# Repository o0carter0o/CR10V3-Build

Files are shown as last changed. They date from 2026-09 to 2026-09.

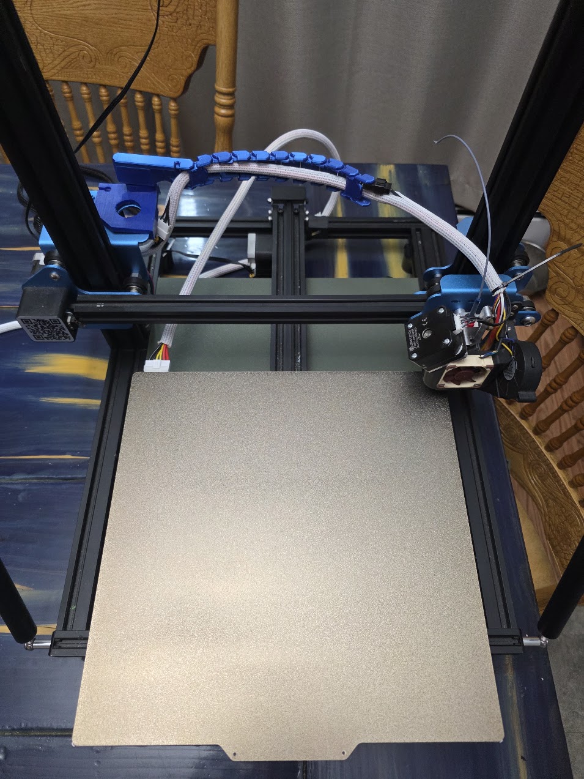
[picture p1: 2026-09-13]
images/20260907_123307.jpg

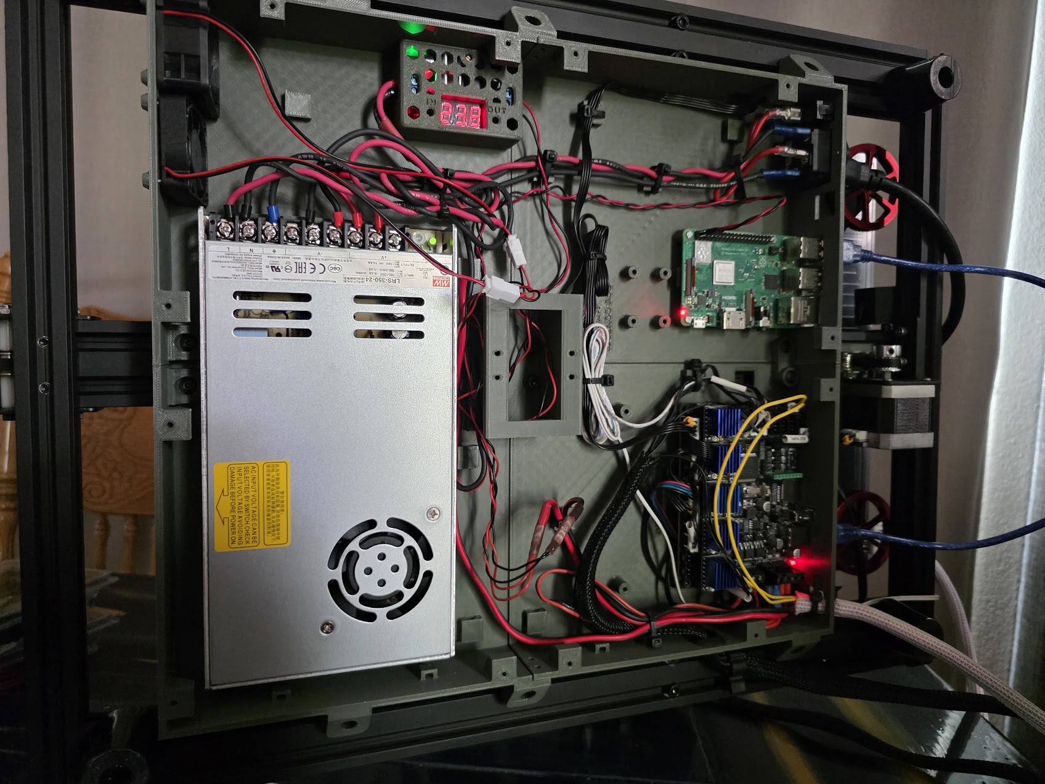
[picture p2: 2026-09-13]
images/20260911_142548.jpg

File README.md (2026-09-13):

# CR-10 V3 Under-Frame Electronics Conversion

This repository documents a CR-10 V3 conversion built around an MKS Robin Nano v3.1, independent dual Z, a Micro Swiss NG direct-drive extruder, CR Touch, and a four-piece printed under-frame electronics enclosure.

Current enclosure release: **v1.1**.

## Repository contents

- [`enclosure/STL/print_ready`](enclosure/STL/print_ready) — nine print-ready enclosure parts
- [`enclosure/STEP/assembled`](enclosure/STEP/assembled) — authoritative assembled STEP
- [`enclosure/STEP/parts_print_orientation`](enclosure/STEP/parts_print_orientation) — editable individual parts oriented for printing
- [`enclosure/STEP/parts_global`](enclosure/STEP/parts_global) — individual parts in installed coordinates
- [`enclosure/Accessories`](enclosure/Accessories) — opening blanks, Robin Nano spacers, and center-support adapter
- [`klipper`](klipper) — reference printer, macro, Mainsail, and Moonraker configuration snapshots
- [`docs/BUILD_GUIDE.md`](docs/BUILD_GUIDE.md) — printer and enclosure build overview
- [`docs/WIRING.md`](docs/WIRING.md) — board assignments and CR Touch wiring
- [`docs/ENCLOSURE_BOM.md`](docs/ENCLOSURE_BOM.md) — enclosure hardware list
- [`docs/ENCLOSURE_NOTES.md`](docs/ENCLOSURE_NOTES.md) — assembly and electrical notes

## Enclosure printing baseline

- 0.4 mm nozzle
- 0.20 mm layers
- At least 4 walls/perimeters
- At least 5 top and bottom layers
- Print the main parts in the supplied orientation
- The main parts are designed to print without supports

The assembled STEP is the authoritative v1.1 geometry. The STL files are the ready-to-print deliverables.

Part filenames use installed machine position, viewed from the front/operator side of the printer.

## Configuration warning

The files in `klipper/` are reference material for this specific machine. They are not a universal drop-in configuration. Verify the board revision, pin assignments, thermistor types, motor directions, travel limits, probe offsets, heater behavior, and emergency shutdown before moving any axis or heating anything.

At minimum, replace the MCU `serial:` path in `printer.cfg` with the path reported by your own controller.

## Safety

This conversion places AC mains wiring and a power supply in a printed enclosure. Use proper strain relief, insulated terminals, protective-earth bonding, fusing, wire sizes, separation, and continuity testing. Mains work should be performed only by someone qualified to do it.

## Attribution

This enclosure is a derivative of HeyRay2's [CR-10 V2 Control Box Eliminator - Standalone Conversion](https://www.thingiverse.com/thing:4347673). See [`ATTRIBUTION.md`](ATTRIBUTION.md).

## License

- STEP, STL, and documentation: [CC BY 4.0](LICENSE-CC-BY-4.0.txt)
- Klipper configuration and original macros: [GPL-3.0-or-later](LICENSE-GPL-3.0.txt)

See [`LICENSE.md`](LICENSE.md) for the file-by-file scope and third-party notices.

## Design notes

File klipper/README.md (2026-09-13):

# Klipper Configuration Snapshot

These files are reference material for this CR-10 V3 conversion. They are not guaranteed to be safe on another printer without review.

Before use:

- Set the correct MCU `serial:` path in `printer.cfg`.
- Confirm every pin assignment against your exact MKS Robin Nano v3.1 board.
- Verify motor direction, endstop state, thermistor type, heater behavior, probe operation, and emergency stop behavior.
- Do not heat or move the printer until the config is checked.

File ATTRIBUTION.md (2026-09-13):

# Attribution

This CR-10 V3 under-frame electronics enclosure is a derivative of:

- **CR-10 V2 Control Box Eliminator - Standalone Conversion**
- Creator: HeyRay2
- Source: https://www.thingiverse.com/thing:4347673
- License: Creative Commons Attribution 4.0 International

The published V1.0 enclosure has been substantially modified for this CR-10 V3 build, including a four-quadrant under-frame layout, MKS Robin Nano v3.1 mounting, Raspberry Pi 3B/3B+ mounting, MKS TS35 v2.0 screen opening, reused Creality mains/pass-through hardware, center support, direct-thread bosses, cable routing, and fan/vent changes.

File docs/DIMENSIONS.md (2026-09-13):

# V1.1 key dimensions and interfaces

- Development source revision: V1.1 publication package
- Closed enclosure height: 45.0 mm
- Shell height: 42.6 mm
- Nominal wall thickness: 3.2 mm
- Nominal ceiling thickness: 2.4 mm
- Primary split datums: X=160 mm, Y=170 mm
- Case placement datum: 40 mm Y setback from the inside face of the front frame extrusion
- Rear lid depth: 189.4 mm
- Fan footprint: 40 × 40 mm; fastener pitch 32 × 32 mm
- M4 frame/T-nut clearance: Ø4.5 mm
- M3 direct-thread pilot: Ø2.6 mm
- Screen cable opening: 19.27 × 10.4 mm
- Keystone throat: 14.8 × 16.5 mm
- Pi wall openings: 2 × 16.2 × 18.0 mm; 1 × 17.4 × 16.4 mm
- Raw-cable entry edge fillets: R0.75 mm at the approved five openings and local raceway mouths
- Rear bonding peg/socket XY clearance: 0.20 mm per side (0.40 mm diametral)
- Rear bonding hardware: M4×10

## V1.1 interface changes

- Left Rear rear keystone replaced by a second Ø17 mm grommet opening.
- Robin Nano mounting now uses four 5 mm spacers in either board position.
- Right Rear keystone moved slightly toward machine center and uses an internal snap-fit cage with a 45° printable underside.
- Right Rear includes a Ø4.5 mm frame-bond access hole and protective-earth symbol.

Part filenames use installed machine position, viewed from the front/operator side of the printer.

## Locked vertical-wall cable-tie anchor

- Single tie channel
- Exact forward/aft mirror symmetry
- Overall anchor width: 8.30 mm
- Projection from wall: 4.50 mm
- Tie gap: 4.20 mm
- Straight-leg section before roof transition: 0.00 mm
- Inner roof faces: 45°
- Outer support face: 45°
- Channel-roof to outer-top distance: 6.00 mm
- Unsupported bridge span: 1.20 mm

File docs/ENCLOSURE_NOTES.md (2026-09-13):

# V1.1 Notes

## Changes from V1.0

- Left Rear: rear keystone replaced by a second Ø17 mm grommet opening.
- Robin Nano: all eight optional mounting bosses now use the short geometry; use four 5 mm spacers in either board position.
- Right Rear: keystone moved slightly toward machine center and given an internal snap-fit cage with a 45° printable underside.
- Right Rear: added a Ø4.5 mm frame-bond access hole and protective-earth symbol.

Part filenames use installed machine position, viewed from the front/operator side of the printer. Earlier internal CAD/package naming had left and right reversed; this repo uses the corrected installed-position names.

## Assembly notes

- Insert the Left Rear keystone from inside the enclosure toward the exterior.
- The built-in zip-tie anchors are intended to print without support. Avoid support material inside the tie channels; it adds cleanup risk without helping the final part.
- Use the supplied print orientation for the shell quadrants and lids.
- Direct-thread the printed pilots carefully. Start screws square to the hole and avoid over-tightening.
- The center support clamps the inner quadrant corners to the central 20×40 extrusion from inside the enclosure.
- Twist the internal switched Line and Neutral run from the inlet/switch area to the PSU.
- Twist or closely couple the internal `+24 V / 0 V` pair from the PSU to the Robin Nano.
- If the keystone carries normal data, an inlet-mounted EMI filter or grounded L-shaped steel divider may be added if desired.
- If Cat6 carries steppers/endstops, keep each motor coil on one twisted pair and place endstop signal/ground on their own pair.

Frame bonding is an optional retrofit in this design and is strongly encouraged when modifying the mains enclosure. The designer's personal solution is a suitable self-tapping screw through the marked hole into the extrusion V-channel with a ring terminal and toothed washer. This permanently marks/cuts the extrusion and is not readily reversible.

Alternatives include enlarging the access for a conductive T-nut and ring terminal, drilling and tapping the frame, routing the bonding wire to another suitable frame location, or bonding the grounded PSU chassis to the printer frame. Any method must make reliable metal-to-metal contact; verify continuity after assembly. Mains work should be performed only by someone qualified to do it.

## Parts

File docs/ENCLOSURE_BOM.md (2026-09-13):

# Hardware BOM — V1.1

## Main components

| Qty | Component |
|---:|---|
| 1 | MKS Robin Nano v3.1 |
| 1 | Mean Well LRS-350-24 PSU |
| 1 | MKS TS35 v2.0 display |
| 1 | Raspberry Pi 3B/3B+ (optional) |
| 3 | 40 mm case fans; thickness and voltage to suit the build |
| 1 | OEM IEC inlet |
| 1 | OEM rocker switch |
| 1 | OEM heated-bed connector |
| 2 | OEM-style grommets for the Ø17 mm cable entries |
| 1 | Keystone jack or included blank (optional) |

## Fasteners

| Qty | Hardware | Use |
|---:|---|---|
| 16 | M3×8 | Four lids |
| 4 | M3×10 | Robin Nano through the included 5 mm spacers |
| 4 | M2.5×5 | Raspberry Pi |
| 4 | M3×8 | PSU-control board |
| 4 | M4×4 | PSU mounting; avoid excessive penetration |
| 8 | M4×10 plus T-nuts | Four exterior mounts and four center-support clamps |
| 1 | M4×10 | Rear quadrant bonding bridge |
| 9 | M3, length to suit fan thickness | Three screws per fan |
| 4 | M3×8 nominal | Optional center-support adapter |

## Printed accessories

Print four `Robin_Nano_Spacer_5mm_M3` spacers for either motherboard position. A ready-to-print 4× set is included.

Pilot standards: M3 direct-thread Ø2.6 mm; M2.5 direct-thread Ø2.2 mm; M4/T-nut clearance Ø4.5 mm.

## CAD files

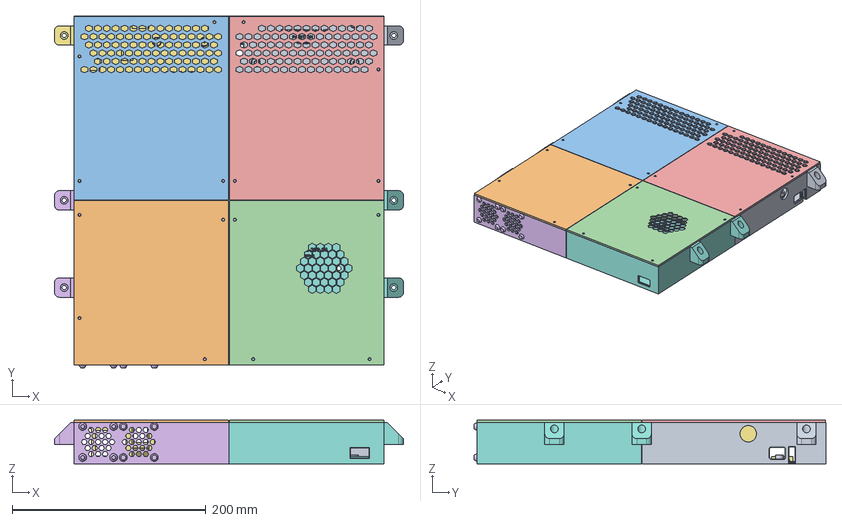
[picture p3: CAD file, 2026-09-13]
enclosure/STEP/assembled/CR10V3_Control_Box_V1.1_Assembled.step
360.0 x 362.8 x 45.0 mm

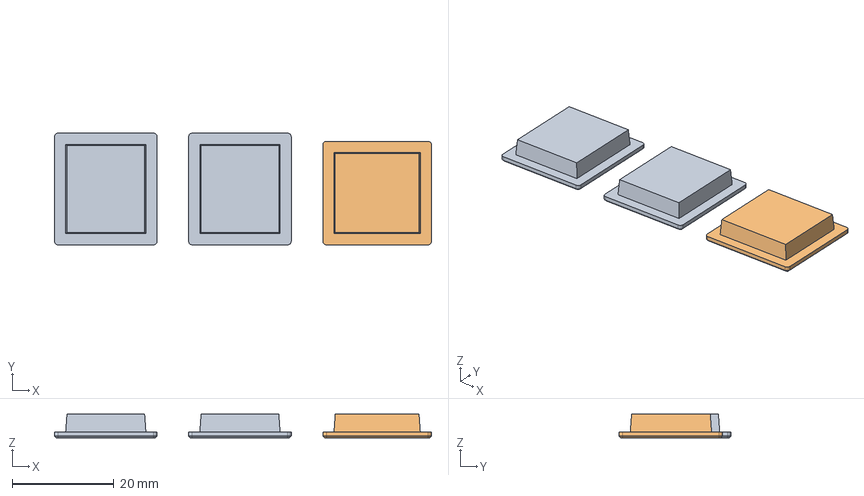
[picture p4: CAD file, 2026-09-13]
enclosure/Accessories/STEP/RPi_Blanks_Full_Set.step
74.2 x 22.0 x 4.70 mm

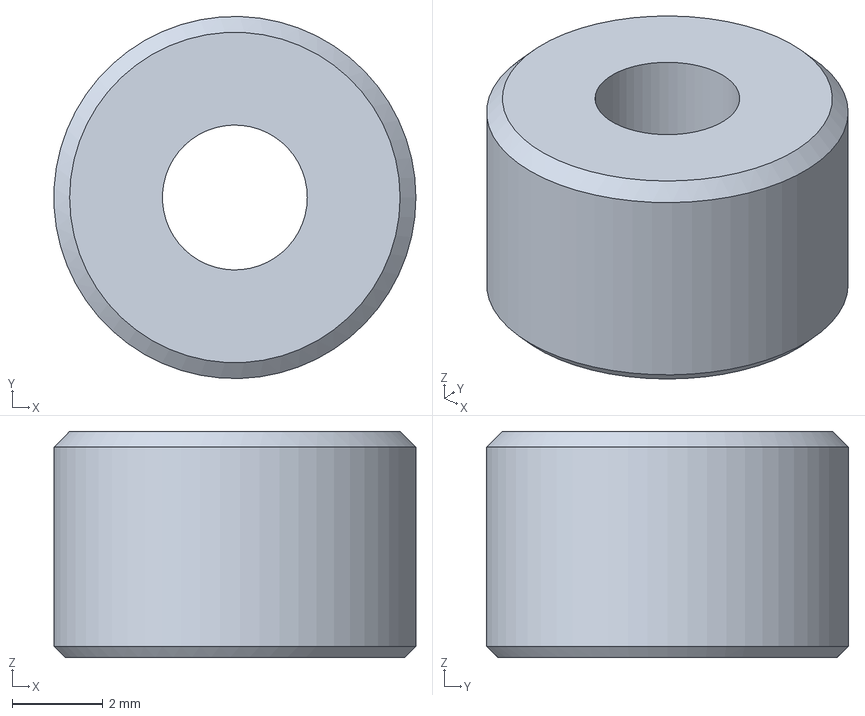
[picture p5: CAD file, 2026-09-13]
enclosure/Accessories/STEP/Robin_Nano_Spacer_5mm_M3.step
7.99 x 8.00 x 5.00 mm

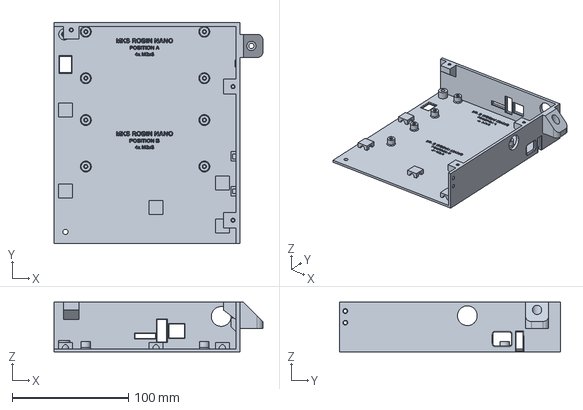
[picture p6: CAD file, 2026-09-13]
enclosure/STEP/parts_global/Shell_Left_Rear_GLOBAL.step
179.9 x 189.8 x 42.6 mm

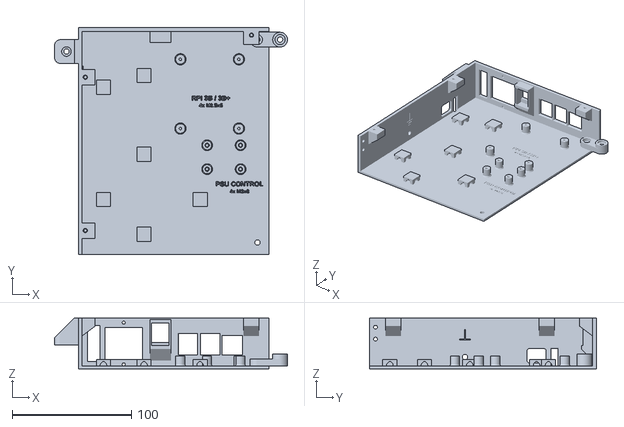
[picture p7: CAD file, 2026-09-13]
enclosure/STL/print_ready/Shell_Right_Rear.stl
195.2 x 189.9 x 42.6

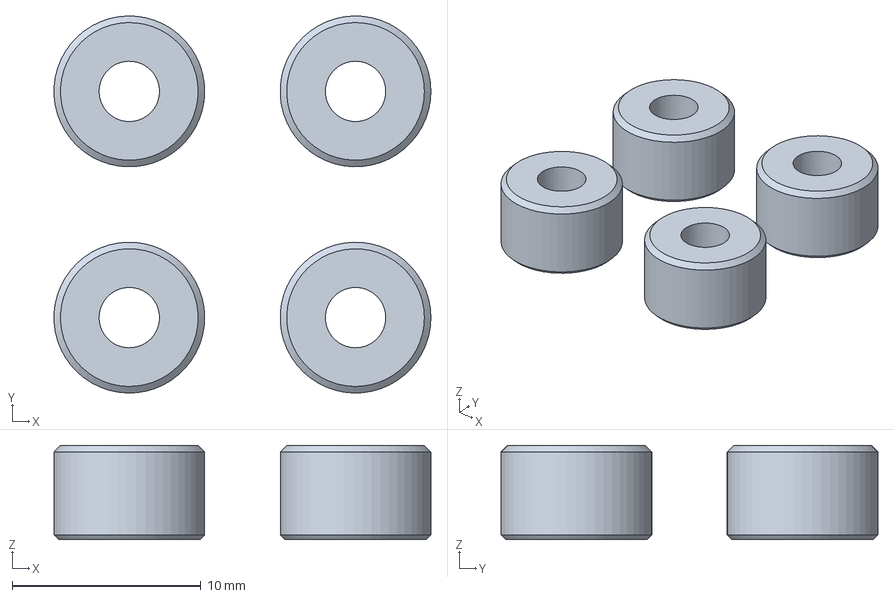
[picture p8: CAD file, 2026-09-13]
enclosure/Accessories/STEP/Robin_Nano_Spacers_4x.step
20.0 x 20.0 x 5.00 mm

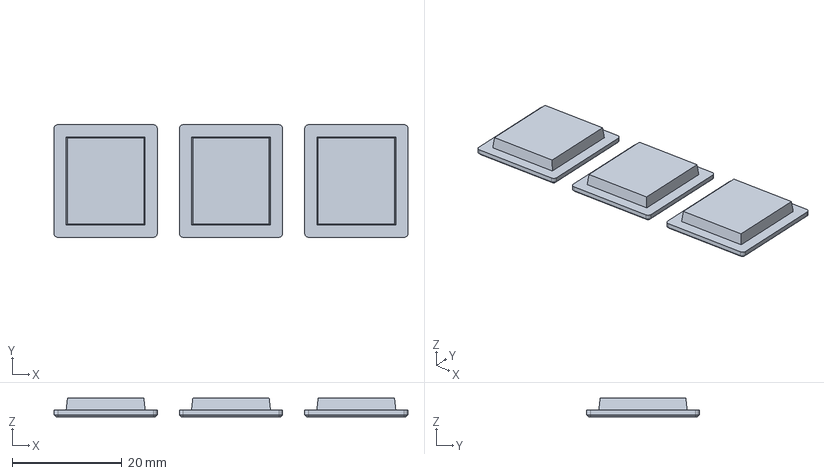
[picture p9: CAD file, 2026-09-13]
enclosure/Accessories/STEP/Keystone_Blanks_3x.step
64.4 x 20.5 x 3.40 mm

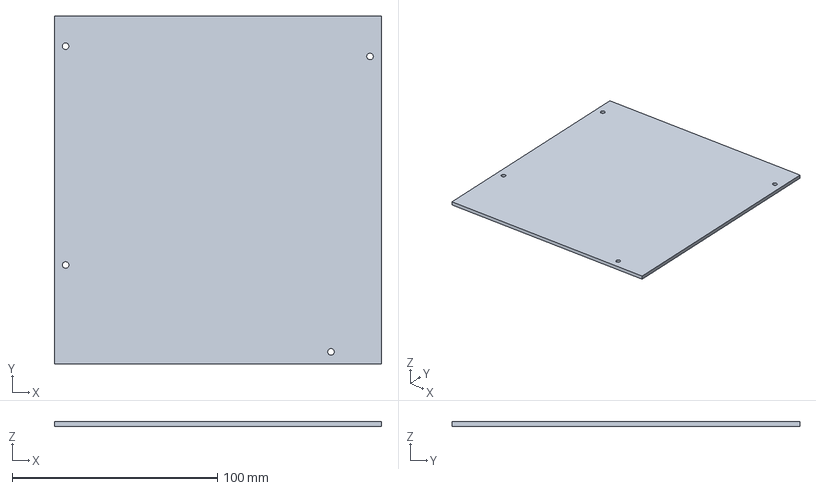
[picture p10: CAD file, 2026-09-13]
enclosure/STEP/parts_global/Lid_Right_Front_GLOBAL.step
159.4 x 169.4 x 2.40 mm

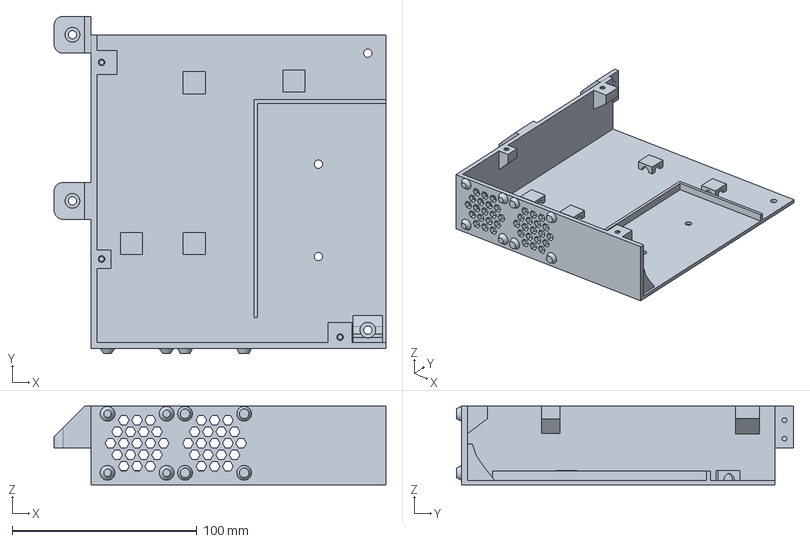
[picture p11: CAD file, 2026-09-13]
enclosure/STEP/parts_print_orientation/Shell_Right_Front.step
179.9 x 182.8 x 42.6 mm

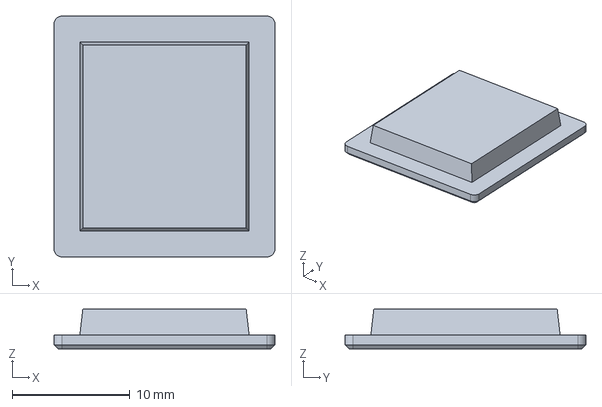
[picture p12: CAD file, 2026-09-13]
enclosure/Accessories/STEP/Keystone_Blank_14p8x16p5.step
18.8 x 20.5 x 3.40 mm

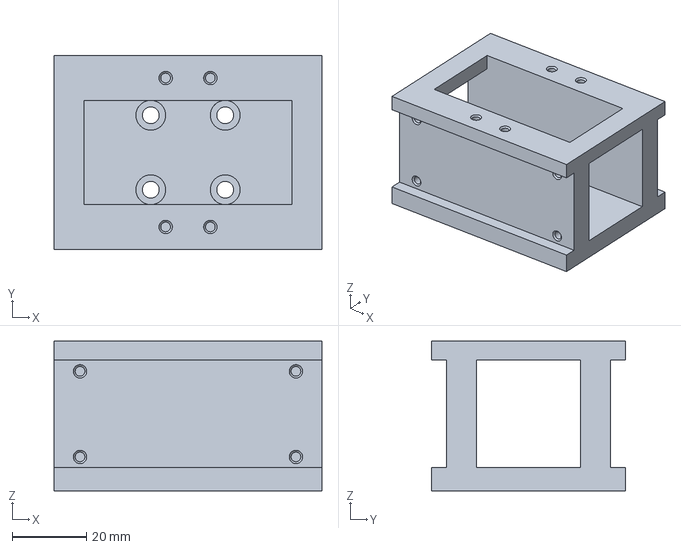
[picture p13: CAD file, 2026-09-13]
enclosure/STEP/parts_global/Center_Support_GLOBAL.step
72.0 x 52.0 x 40.2 mm

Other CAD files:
enclosure/STEP/parts_print_orientation/Shell_Left_Rear.step
enclosure/STEP/parts_global/Shell_Right_Rear_GLOBAL.step
enclosure/STEP/parts_print_orientation/Shell_Right_Rear.step
enclosure/STL/print_ready/Shell_Left_Rear.stl
enclosure/STL/print_ready/Shell_Right_Front.stl
enclosure/STEP/parts_print_orientation/Lid_Right_Front.step
enclosure/STL/print_ready/Lid_Right_Front.stl
enclosure/Accessories/STEP/CenterSupport_AdapterPlate_Generic_6mm.step
enclosure/Accessories/STEP/RPi_Blank_16p2x18p0.step
enclosure/Accessories/STEP/RPi_Blank_17p4x16p4.step
enclosure/Accessories/STL/CenterSupport_AdapterPlate_Generic_6mm.stl
enclosure/Accessories/STL/Keystone_Blank_14p8x16p5.stl
enclosure/Accessories/STL/Keystone_Blanks_3x.stl
enclosure/Accessories/STL/RPi_Blank_16p2x18p0.stl
enclosure/Accessories/STL/RPi_Blank_17p4x16p4.stl
enclosure/Accessories/STL/RPi_Blanks_Full_Set.stl
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

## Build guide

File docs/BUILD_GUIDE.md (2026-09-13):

# CR-10 V3 Build Guide

This build converts a CR-10 V3 from the external OEM electronics box to an under-frame electronics enclosure.

## Major hardware

| Area | Part |
|---|---|
| Controller | MKS Robin Nano v3.1 |
| Screen | MKS TS35 v2.0 |
| Host | Raspberry Pi 3B/3B+ |
| PSU | Mean Well LRS-350-24 |
| Extruder | Micro Swiss NG direct drive |
| Probe | CR Touch |

## Enclosure

The enclosure is split into four printed shell quadrants plus four lids and a center support. The assembled STEP is the source of truth for the released V1.1 geometry:

`enclosure/STEP/assembled/CR10V3_Control_Box_V1.1_Assembled.step`

Print-ready STL files are in:

`enclosure/STL/print_ready/`

The case is designed around a 45 mm closed height so the top sits flush with the top of the lower frame extrusions while maintaining about 5 mm of ground clearance with 30 mm feet.

Part filenames use installed machine position, viewed from the front/operator side of the printer.

## Printing baseline

- 0.4 mm nozzle
- 0.20 mm layer height
- PLA, PETG, ASA, or similar material appropriate for your printer environment
- At least 4 walls/perimeters
- At least 5 top and bottom layers
- Print the parts in the supplied STL orientation
- Do not add supports for the built-in zip-tie anchors; the anchor roof geometry was designed around short spans and angled faces.

Inspect screw pilots before assembly. The design uses direct-thread printed holes, not heat-set inserts.

## Assembly notes

- Mount the PSU directly through the enclosure ceiling.
- Use short PSU screws and verify they cannot penetrate too far into the power supply.
- Use M4 hardware and T-nuts for the frame mounts and center support clamp.
- Use M3 hardware for lids, board mounts, fans, and printed accessories unless noted otherwise.
- Use M2.5 hardware for the Raspberry Pi.
- Keep AC mains wiring physically separated from low-voltage and signal wiring.
- Check continuity, strain relief, earth bonding, and insulation before applying mains power.

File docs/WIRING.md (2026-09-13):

# Wiring Notes

These notes document the intended CR-10 V3 electronics conversion. Verify against your own board silkscreen and pinout before powering anything.

## Controller

- Board: MKS Robin Nano v3.1
- Drivers: TMC2209 UART on X, Y, Z, E0, and E1
- Independent Z: second Z motor connected to E1
- FAN0: hot-end heatsink fan
- FAN1: layer cooling fan
- HE1 / spare heater output: case-fan testing/control target

## CR Touch

The OEM harness uses a 3-pin probe connector plus a separate D11 signal.

| CR Touch / harness side | Robin Nano v3.1 target |
|---|---|
| 3-pin probe connector | Z- header: PC8, GND, 5V |
| D11 signal | PA8 on BLTouch/sensor header |

The PA8 pin is the square pin on the referenced board diagram used during the build.

## Endstops and filament sensor

- X and Y endstops use the normal endstop inputs.
- The OEM two-pin endstop plug may need to be repinned into a three-pin housing.
- Filament sensor is assigned to Z+ in the working build notes.

## Power

- Main PSU: 24 VDC output from Mean Well LRS-350-24
- Raspberry Pi power preference: dedicated 24 V to 5 V buck converter
- Case fans: planned through a 24 V to 12 V buck when using 12 V fans
- Twist or closely couple the switched AC line/neutral run and the PSU-to-controller 24 V/0 V pair where practical.
- Keep low-voltage signal wiring and mains wiring on separate paths inside the enclosure.

## Safety

This enclosure contains mains voltage. Use insulated terminals, appropriate wire gauge, proper strain relief, protective earth bonding, fusing, and separation between mains and low-voltage wiring.

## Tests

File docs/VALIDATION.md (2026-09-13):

# V1.1 package validation

- Development source: **V1.1 publication package**
- Assembled STEP solid count: **9**
- All assembled solids valid: **True**
- Assembled STEP SHA-256: `dbb14a18ec21b83e18e4bfb6b02dfbb968d4819d58f147e674b58dc16fda51fa`

## Shell-to-shell intersection volumes
- Shell_Left_Front x Shell_Right_Front: **0.000000000 mm³**
- Shell_Left_Front x Shell_Left_Rear: **0.000000000 mm³**
- Shell_Left_Front x Shell_Right_Rear: **0.000000000 mm³**
- Shell_Right_Front x Shell_Left_Rear: **0.000000000 mm³**
- Shell_Right_Front x Shell_Right_Rear: **0.000000000 mm³**
- Shell_Left_Rear x Shell_Right_Rear: **0.000000000 mm³**

## Main print-ready STLs
- `Shell_Left_Front.stl`: watertight=True, components=1, extents=[179.85, 180.0, 42.6] mm, on-bed=True, 220×220×240-fit=True
- `Shell_Right_Front.stl`: watertight=True, components=1, extents=[179.85, 182.8, 42.6] mm, on-bed=True, 220×220×240-fit=True
- `Shell_Left_Rear.stl`: watertight=True, components=1, on-bed=True, 220×220×240-fit=True
- `Shell_Right_Rear.stl`: watertight=True, components=1, on-bed=True, 220×220×240-fit=True
- `Lid_Left_Front_PSU.stl`: watertight=True, components=1, extents=[159.4, 169.4, 11.1] mm, on-bed=True, 220×220×240-fit=True
- `Lid_Right_Front.stl`: watertight=True, components=1, extents=[159.4, 169.4, 2.4] mm, on-bed=True, 220×220×240-fit=True
- `Lid_Left_Rear.stl`: watertight=True, components=1, extents=[159.4, 189.4, 2.4] mm, on-bed=True, 220×220×240-fit=True
- `Lid_Right_Rear.stl`: watertight=True, components=1, extents=[159.4, 189.4, 2.4] mm, on-bed=True, 220×220×240-fit=True
- `Center_Support.stl`: watertight=True, components=1, extents=[72.0, 52.0, 40.2] mm, on-bed=True, 220×220×240-fit=True

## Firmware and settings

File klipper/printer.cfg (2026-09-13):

# CR-10 V3 / MKS Robin Nano v3.1 reference configuration
# Review and verify before use.

[include mainsail.cfg]
[include macros.cfg]

[mcu]
serial: /dev/serial/by-id/REPLACE_WITH_YOUR_MCU_BY_ID

[printer]
kinematics: cartesian
max_velocity: 400
max_accel: 4250
max_z_velocity: 20
max_z_accel: 150

[stepper_x]
step_pin: PE3
dir_pin: PE2
enable_pin: !PE4
microsteps: 16
rotation_distance: 40
endstop_pin: !PA15
position_endstop: 0
position_max: 300
homing_speed: 80

[tmc2209 stepper_x]
uart_pin: PD5
run_current: 0.800
stealthchop_threshold: 999999

[stepper_y]
step_pin: PE0
dir_pin: PB9
enable_pin: !PE1
microsteps: 16
rotation_distance: 40
endstop_pin: !PD2
position_endstop: 0
position_max: 300
homing_speed: 80

[tmc2209 stepper_y]
uart_pin: PD7
run_current: 0.800
stealthchop_threshold: 999999

[stepper_z]
step_pin: PB5
dir_pin: PB4
enable_pin: !PB8
microsteps: 16
rotation_distance: 8
endstop_pin: probe:z_virtual_endstop
position_min: -5
position_max: 400

[tmc2209 stepper_z]
uart_pin: PD4
run_current: 0.800
stealthchop_threshold: 999999

[stepper_z1]
step_pin: PD6
dir_pin: PD3
enable_pin: !PB3
microsteps: 16
rotation_distance: 8

[tmc2209 stepper_z1]
uart_pin: PD9
run_current: 0.800
stealthchop_threshold: 999999

[extruder]
step_pin: PD15
dir_pin: PD14
enable_pin: !PC7
microsteps: 16
rotation_distance: 7.71
nozzle_diameter: 0.400
filament_diameter: 1.750
heater_pin: PC3
sensor_type: EPCOS 100K B57560G104F
sensor_pin: PC1
control: pid
pid_Kp: 22.2
pid_Ki: 1.08
pid_Kd: 114
min_temp: 0
max_temp: 285

[tmc2209 extruder]
uart_pin: PD8
run_current: 0.650
stealthchop_threshold: 999999

[heater_bed]
heater_pin: PA0
sensor_type: Generic 3950
sensor_pin: PC0
control: pid
pid_Kp: 54.027
pid_Ki: 0.770
pid_Kd: 948.182
min_temp: 0
max_temp: 120

[bltouch]
sensor_pin: ^PC8
control_pin: PA8
x_offset: 0
y_offset: 0
z_offset: 0

[safe_z_home]
home_xy_position: 105,150
speed: 80
z_hop: 10
z_hop_speed: 10

[bed_mesh]
speed: 120
horizontal_move_z: 5
mesh_min: 20,20
mesh_max: 280,280
probe_count: 5,5

[z_tilt]
z_positions:
    -30,150
    330,150
points:
    60,150
    240,150
speed: 120
horizontal_move_z: 10
retries: 5
retry_tolerance: 0.02

[fan]
pin: PB1

[heater_fan hotend_fan]
pin: PB0
heater: extruder
heater_temp: 50.0

[fan_generic case_fans]
pin: PA1
kick_start_time: 0.5

[filament_switch_sensor filament_sensor]
switch_pin: ^PA4
pause_on_runout: true

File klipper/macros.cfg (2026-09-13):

# CR-10 V3 reference macros

[gcode_macro _USER_VARS]
variable_bed_temp: 60
variable_extruder_temp: 210
variable_standby_nozzle: 150
gcode:

[gcode_macro CASE_FANS_ON]
description: Turn case fans on
gcode:
  SET_FAN_SPEED FAN=case_fans SPEED=1.0

[gcode_macro CASE_FANS_OFF]
description: Turn case fans off
gcode:
  SET_FAN_SPEED FAN=case_fans SPEED=0.0

[gcode_macro CASE_FANS_TOGGLE]
description: Toggle case fans
gcode:
  {% set fan = printer["fan_generic case_fans"].speed|float %}
  {% if fan > 0 %}
    CASE_FANS_OFF
  {% else %}
    CASE_FANS_ON
  {% endif %}

[gcode_macro START_PRINT]
description: Bed heat, soak, home, mesh, nozzle heat, purge
gcode:
  {% set bed = params.BED_TEMP|default(printer["gcode_macro _USER_VARS"].bed_temp)|float %}
  {% set noz = params.EXTRUDER_TEMP|default(printer["gcode_macro _USER_VARS"].extruder_temp)|float %}
  {% set standby = printer["gcode_macro _USER_VARS"].standby_nozzle|float %}
  M140 S{bed}
  M104 S{standby}
  G90
  M83
  M190 S{bed}
  G4 S60
  G28
  Z_TILT_ADJUST
  G28 Z
  BED_MESH_CALIBRATE
  M109 S{noz}
  LINE_PURGE

[gcode_macro END_PRINT]
description: Safe shutdown moves after print
gcode:
  M400
  G91
  G1 E-2 F1800
  G1 Z10 F1200
  G90
  G1 X10 Y290 F6000
  M104 S0
  M140 S0
  M106 S0
  CASE_FANS_OFF
  M84

[gcode_macro LINE_PURGE]
description: Basic purge line
gcode:
  G92 E0
  G1 Z0.28 F1200
  G1 X5 Y10 F6000
  G1 X5 Y200 E12 F1200
  G1 X6 Y200 F6000
  G1 X6 Y10 E12 F1200
  G92 E0

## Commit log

2026-09-13 Publish CR-10 V3 build package v1.0
    [CR10V3_Control_Box_V1.0_Assembled.step, CenterSupport_AdapterPlate_Generic_6mm.step, CenterSupport_AdapterPlate_Generic_6mm.stl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]
2026-09-13 Update enclosure package to v1.1
    [CR10V3_Control_Box_V1.0_Assembled.step, CR10V3_Control_Box_V1.1_Assembled.step, Robin_Nano_Spacer_5mm_M3.step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]
2026-09-13 Correct enclosure left-right part naming
    [Lid_Left_Front_PSU.step, Lid_Left_Front_PSU.stl, Lid_Left_Front_PSU_GLOBAL.step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]
